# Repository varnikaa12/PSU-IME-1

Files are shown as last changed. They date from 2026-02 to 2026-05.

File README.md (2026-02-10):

# PSU-IME-1

The Harold & Inge Marcus Department of Industrial & Manufacturing Engineering at The Pennsylvania
State University is launching a new course in industrial automation and robotics. They are seeking a low-
cost, open-source, and modular tabletop training platform that supports hands-on learning in industrial
control systems, programmable logic controllers (PLCs), system integration, and digital twins while
currently lacking an affordable, modular physical platform for lab instruction. The department's existing
commercial training devices provide strong functionality but are too expensive, closed, and difficult to
modify or repair, limiting their suitability for long-term academic use and iterative student prototyping.
The student team will design and prototype an MVP tabletop production cell that sorts small colored
cylinders representing workpieces in a manufacturing line. Key requirements include modular and
reconfigurable mechanical design, predominantly 3D-printed or easily fabricated components, low
assembly complexity, 24V PLC compatibility using ladder logic via OpenPLC on RevPi hardware,
minimized custom electronics, and sourcing of all major components from established suppliers. In-scope
activities include mechanical design using primarily 3D-printed components, integration of 24 V
electrical hardware aligned with IEC 61131-2/3, PLC-based control logic, industrial sensor integration,
and development of a digital twin in ProtoTwin. Stretch goals include multi-size LEGO sorting, a bulk
hopper with automatic singulation, and interoperability with other tabletop cells to create an end-to-end
automated workflow.
Core deliverables include: (1) a working physical prototype suitable for classroom demonstrations, (2)
complete open-source documentation including CAD, bill of materials, assembly drawings, wiring
diagrams, and source code, and (3) a validated ProtoTwin model of the system. Key budget requirements
include a target build cost of approximately $100 per unit with an absolute maximum of $500. Expected
benefits include substantial cost reduction relative to commercial trainers, improved instructional quality
through hands-on interaction with industrial hardware, reduced setup and maintenance effort, and a
flexible open-source platform that future cohorts can modify, repair, and extend. The project is planned
for 15 weeks, starting January 12th and ending by May 3rd with the Capstone Showcase and Program
Closeout Review.

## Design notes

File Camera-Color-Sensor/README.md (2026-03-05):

# Camera Color Sensor & Recognition for Revolution Pi

This system provides high-accuracy real-time color recognition using a Random Forest model. It is designed to relay color data to a **Revolution Pi (RevPi)** via **Modbus TCP**, allowing for integration with **CODESYS** and industrial ladder logic.

## Key Features

- **Advanced AI Model**: Uses a Random Forest Classifier trained on BGR and HSV features (Version 2.0).
- **Lighting Robustness**: HSV color space integration helps distinguish colors (like Red vs. Brown) in varying light.
- **Modbus TCP Integration**:
  - **`color_recognition.py`**: Runs on a PC, acts as a Modbus Server (Slave).
  - **`color_recognition_revpi.py`**: Runs on the RevPi, acts as a Modbus Client (Master).
- **Camera Selection**: Automatically identifies Windows device names (e.g., "Integrated Camera", "UC60 Video").
- **Visual Feedback**: Live feed includes a focus box, certainty percentage, and a color patch.

## Setup & Installation

### 1. Prerequisites
- Python 3.10+
- Modbus TCP enabled in CODESYS (if using RevPi)

### 2. Install Dependencies
```bash
pip install -r requirements.txt
```

### 3. Training the Model
1. Place your categorized images in the `dataset/` folder.
2. Run the training script:
   ```bash
   python train_model.py
   ```
   This generates `color_model.pkl` using the advanced feature extraction.

## Usage

### Local Testing (PC as Server)
Run this script to test the camera and host the Modbus data:
```bash
python color_recognition.py
```
- **Modbus Address**: The color ID is written to **Holding Register 0**.
- **Note**: Run as Administrator on Windows to allow port 502 access.

### Production (RevPi as Client)
Run this script on the RevPi to capture video and write to a PLC/CODESYS:
```bash
python color_recognition_revpi.py
```

## Color Mapping Reference
The following IDs are sent over Modbus to CODESYS:

| ID | Color | ID | Color |
|:---|:---|:---|:---|
| 1 | Red | 6 | Violet |
| 2 | Green | 7 | Black |
| 3 | Blue | 8 | White |
| 4 | Yellow | 9 | Grey |
| 5 | Orange | 10 | Brown |

## Project Structure
- `camera_utils.py`: Hardware-level camera discovery and naming.
- `train_model.py`: Random Forest training with HSV feature extraction.
- `color_recognition.py`: Primary PC-side script (Modbus Server).
- `color_recognition_revpi.py`: RevPi-side script (Modbus Client).
- `requirements.txt`: Project dependencies (OpenCV, Scikit-learn, pyModbusTCP).

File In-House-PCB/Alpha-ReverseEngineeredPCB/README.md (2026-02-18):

# Line Sorter

**Project Name:** Line Sorter  
**Project Version:** `#7c7d5a3e`  
**Project URL:** https://www.flux.ai/re7rovm/line-sorter  

Line Sorter is a 24 V field I/O board that interfaces a PLC with sensors and actuators, providing protected digital inputs, low‑side MOSFET outputs for inductive loads, and a buffered analog sensor output. [file:31]

---

## 1. Overview

- **Purpose:** Condition 24 V field signals and drive multiple “line” loads (such as solenoids or relays) under PLC control. [file:31]  
- **System context:** The board sits between a PLC and field devices, converting PLC I/O into robust, protected connections for sensors and actuators. [file:31]  
- **Current status:** Rev `#7c7d5a3e` design with mapped nets and driver stages as described below. [file:31]

---

## 2. System Architecture

The Line Sorter PCB is organized into three main functional blocks: power conversion, PLC‑side I/O, and field‑side drivers/sensors. [file:31]

- **Power path:** 24 V input enters through J1, passes a fuse (F1) and protection diodes (D1, D2), and is split into 24Va and 24Vs rails with bulk and high‑frequency decoupling via C1 and C4. [file:31]  
- **DC‑DC conversion:** A TPS54302 buck regulator (U2) converts the 24Vs rail down to a 9 V rail using L1, C8, and feedback resistors R25 and R26. [file:31]  
- **Auxiliary supply:** A 5V_AUX rail is derived from the 9 V rail through an LDO regulator, powering the analog buffer op‑amp (U3) used for the color sensor signal. [file:31]  
- **PLC interface:** Digital inputs from the field are conditioned and routed into PLC input pins on U1, while PLC output pins from U1 drive the gates of MOSFET low‑side drivers. [file:31]  
- **Field connections:** Loads (e.g., solenoids) connect to J9–J13, and a color sensor connects to J15; each output or sensor line has defined return paths and protection components. [file:31]

---

## 3. Electrical Specifications

- **Input supply:** 24 V nominal via J1, protected by F1 and diodes D1/D2, generating 24Va and 24Vs rails. [file:31]  
- **Intermediate rail:** 9 V rail generated by TPS54302 buck (U2) with L1 and C8. [file:31]  
- **Auxiliary rail:** 5V_AUX derived from 9 V by an LDO to power analog circuitry (U3). [file:31]  
- **Digital inputs:** Multiple 24 V field inputs (I1, I2, I3, I5, I6, I7) feeding PLC inputs on U1 through series diodes and resistors plus pulldown resistors. [file:31]  
- **Outputs:** Five low‑side MOSFET driver channels (Q1–Q5) switching 24Va loads on connectors J9–J13, with flyback diodes for inductive loads. [file:31]

(Exact currents, voltage ranges, and derating should be filled in once the component ratings and requirements are finalized.)

---

## 4. Files and Structure

(Adjust naming to your repo/Flux export.)

- `schematic/` – Schematic source and PDF  
- `pcb/` – Layout and 3D view  
- `manufacturing/` – Gerber, drill, fabrication notes  
- `assembly/` – BOM, pick‑and‑place, assembly instructions  
- `docs/` – Additional documentation, test notes, images

---

## 5. Connectors and Pinout

Fill in exact pin numbers and names from your schematic; the notes below describe the functional roles. [file:31]

### J1 – 24 V Power Input

- VIN (24 V nominal) passes through F1 and protection diodes D1/D2 to form the 24Va/24Vs rails. [file:31]  
- GND connects to the board ground, shared with MOSFET source nodes and PLC 0 V returns. [file:31]

### J3–J8 – Digital Field Inputs (I1, I2, I3, I5, I6, I7)

Each connector provides a 24 V input channel plus a dedicated 0 V return for a PLC input. [file:31]

- Field input pin: goes through a series diode (D8–D13) and resistor (R11–R16) into a PLC input pin on U1 (pins 5–11). [file:31]  
- 0 V return: matches a specific 0 V node (e.g., I1_0V, I2_0V, etc.) and ties back to system GND. [file:31]  
- Pulldown resistors R17–R22 provide defined off‑state behavior for the PLC inputs. [file:31]

### J9–J13 – Line Outputs (Low‑Side Driven Loads)

Each connector is associated with one MOSFET driver Q1–Q5. [file:31]

- Pin 1: 24Va high side supply for the load. [file:31]  
- Pin 2: Switched low side (Qx_SW), which is the MOSFET drain node (Qx:D) and the load return. [file:31]  
- Each MOSFET source (Qx:S) connects to GND and Qx_0V net. [file:31]  
- Flyback diode Dx clamps Qx_SW to Qx_0V to protect against inductive kick when switching off inductive loads. [file:31]

### J15 – Color Sensor Connector

- 9 V supply and GND rails provided for the external color sensor module. [file:31]  
- SENS_SIG returned to the board, buffered by op‑amp U3, and routed to PLC analog input node PLC_I4_AIN. [file:31]

(Add exact pin numbering and orientation once you finalize the schematic annotation.)

---

## 6. PCB Manufacturing Notes

(To be completed with actual mechanical data.)

- Board size: `WIDTH × HEIGHT mm`  
- Layers: `N` layers  
- Material/thickness: e.g., FR‑4, 1.6 mm  
- Copper weight: e.g., 1 oz outer, 1 oz inner  
- Finish: ENIG / HASL  
- Mask/silkscreen: colors and sides  
- Special requirements: appropriate creepage/clearance for 24 V, mounting holes, slots, etc.

---

## 7. Assembly Information

- **BOM:** Contains F1, D1–D13, U1, U2, U3, Q1–Q5, L1, C1, C4, C8, feedback and gate resistors, and connectors J1–J15. [file:31]  
- **Polarity/orientation:**  
  - Diodes D1–D13, MOSFETs Q1–Q5, and electrolytic capacitors must be oriented correctly. [file:31]  
  - ICs U1, U2, U3 must align with their pin‑1 indicators. [file:31]  
- **Assembly order:** Recommended to populate small SMD parts first (resistors, diodes, ICs), then larger components and connectors (L1, terminals Jx, fuse F1). [file:31]

---

## 8. Functional Description

- **Power stage:** 24 V input is fused and protected before feeding 24Va/24Vs; TPS54302 buck converts 24Vs to 9 V, and an LDO produces 5V_AUX for analog circuitry. [file:31]  
- **Digital inputs:** Field 24 V inputs are diode‑ and resistor‑limited before the PLC, with pulldowns to ensure defined off levels. [file:31]  
- **Output drivers:** PLC outputs drive MOSFET gates via series resistors R1–R5, with gate pulldowns R6–R10; MOSFET drains switch the load low side at J9–J13, and diodes D3–D7 provide flyback protection. [file:31]  
- **Analog sensor path:** A color sensor on J15 is powered from 9 V and GND, with its signal buffered by U3 and sent to PLC analog input PLC_I4_AIN. [file:31]

---

## 9. Testing and Bring‑Up

- Verify no short between 24 V and GND at J1 before powering.  
- Power up with a current‑limited 24 V supply and confirm the presence of 9 V and 5V_AUX rails. [file:31]  
- Check PLC input channels by applying known 24 V signals to J3–J8 and observing corresponding PLC inputs. [file:31]  
- Test each line output by connecting a dummy load (e.g., lamp or resistor) on J9–J13 and toggling the corresponding PLC output, watching for correct switching and absence of over‑current or overheating. [file:31]

---

## 10. Tools and License

- **CAD tool:** Flux (project URL above).

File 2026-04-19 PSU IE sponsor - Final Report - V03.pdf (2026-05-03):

# PSU IME Capstone #1

### Final Report

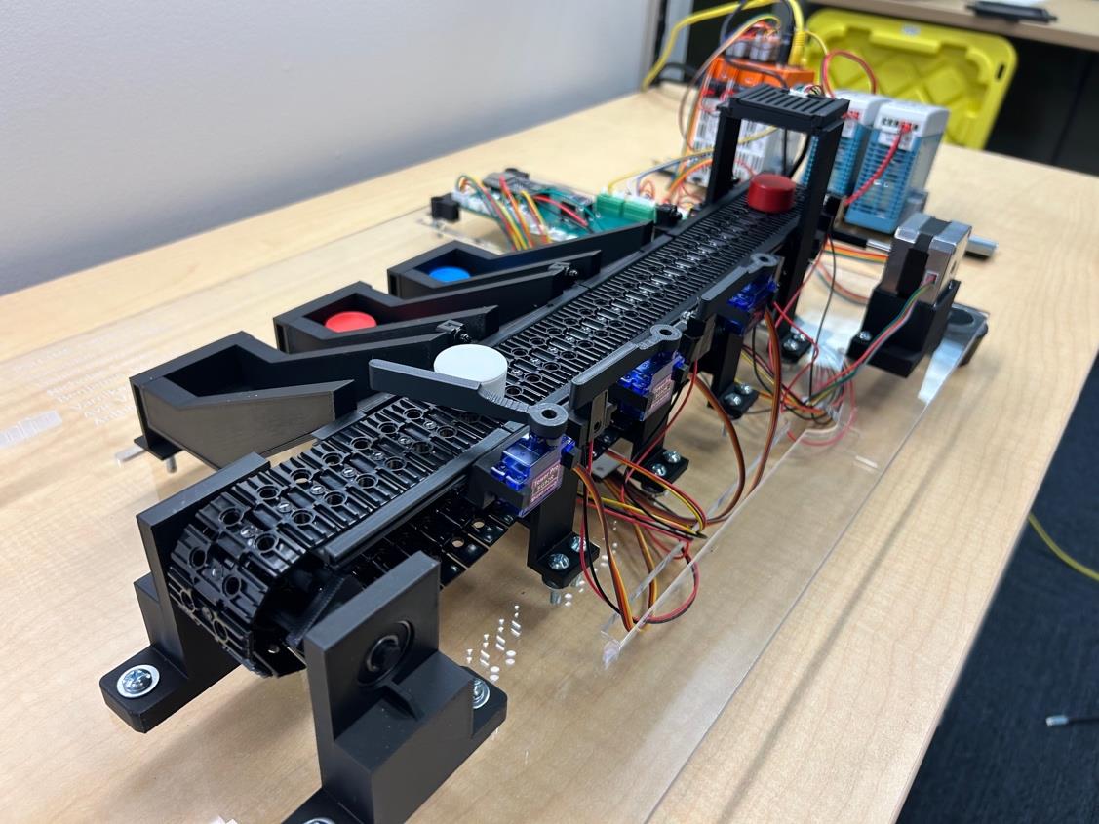
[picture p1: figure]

2026-04-26

Figure 1. Final CAD Assembly

Submitted to:
Prof. Brian Thomas Zajac
344 Leonhard Building
The Pennsylvania State University Park, PA 16802
Submitted by:
Nicholas Savoca, Benjamin Johnston, Daniel Pellizzari, Varnikaa Arora, Anthony Ottaviano, Avie Vasantlal

Advisor:
Prof. Brian Thomas Zajac

Y N
☐ | ☒ | Intellectual Property Rights Agreement Applies
☐ | ☒ | Non-Disclosure Agreement Applies

# Executive Summary

The Harold & Inge Marcus Department of Industrial & Manufacturing Engineering at The Pennsylvania State University is launching a new course in industrial automation and robotics. They are seeking a low-cost, open-source, and modular tabletop training platform that supports hands-on learning in industrial control systems, programmable logic controllers (PLCs), system integration, and digital twins while currently lacking an affordable, modular physical platform for lab instruction. The department's existing commercial training devices provide strong functionality but are too expensive, closed, and difficult to modify or repair, limiting their suitability for long-term academic use and iterative student prototyping.

The student team designed and prototyped an MVP tabletop production cell that sorts small colored cylinders representing workpieces in a manufacturing line. Key requirements include modular and reconfigurable mechanical design, predominantly 3D-printed or easily fabricated components, low assembly complexity, 24V PLC compatibility using ladder logic via OpenPLC on RevPi hardware, minimized custom electronics, and sourcing of all major components from established suppliers. In-scope activities include mechanical design using primarily 3D-printed components, integration of 24 V electrical hardware aligned with IEC 61131-2/3, PLC-based control logic, industrial sensor integration, and development of a digital twin in ProtoTwin. Stretch goals include multi-size LEGO sorting, a bulk hopper with automatic singulation, and interoperability with other tabletop cells to create an end-to-end automated workflow.

Core deliverables include: (1) a working physical prototype suitable for classroom demonstrations, (2) complete open-source documentation including CAD, bill of materials, assembly drawings, wiring diagrams, and source code, and (3) a validated ProtoTwin model of the system. Key budget requirements include a target build cost of approximately $100 per unit with an absolute maximum of $500. Expected benefits include substantial cost reduction relative to commercial trainers, improved instructional quality through hands-on interaction with industrial hardware, reduced setup and maintenance effort, and a flexible open-source platform that future cohorts can modify, repair, and extend. The project is planned for 15 weeks, starting January 12th

and ending by May 3rd
with the Capstone Showcase and Program Closeout Review.

In order to be efficient, we divided our group into three subgroups, which were Mechanical, Electrical, and Software, which enabled parallel development. The design process utilized decision matrices to prioritize cost-efficiency and modularity. The team delivered a physical prototype mounted on a laser-cut acrylic baseplate with a custom 24V PCBA, modular 3D-printed components, and a CODESYS Function Block control program deployed on a RevPi. A few of the stretch goals were reserved for future development, but primary deliverables of CAD files, BOM, and source code were completed and uploaded to an open-source GitHub repository. Financially, the project achieved its goal of remaining under the $500 maximum budget constraint, achieving a final per-unit cost of $325.97. This represents an approximate 76.5% cost reduction compared to the $1,387 commercial Fischertechnik equivalent (Studica, n.d.), successfully proving the viability of a highly affordable, open-source educational platform.

# Table of Contents

# 1.0 Introduction

The Harold & Inge Marcus Department of Industrial & Manufacturing Engineering (IME) at Penn State emphasizes hands-on laboratory experiences that prepare students to design, control, and improve modern manufacturing systems (About the Department, 2021). To support a new course in industrial automation and robotics, the sponsor seeks a tabletop training platform that exposes students to realistic industrial technologies such as sensors, actuators, and programmable logic controllers (PLCs), while remaining low-cost, open-source, and easy to modify for future use. As part of this effort, the project will adapt and “open up” the existing Fischertechnik line sorter concept by recreating a functionally similar line using predominantly 3D-printed and readily sourced components, and by releasing all CAD, electrical documentation, and control code as open-source artifacts so that other instructors and students can study, replicate, and extend the design.

Existing commercial tabletop “smart factory” trainers, including proprietary Fischertechnik-based systems (fischertechnik, 2016), demonstrate that compact production cells are effective for teaching PLC programming, sequencing, and system integration, but these systems are relatively expensive and closed, limiting their ability in iterative student experimentation and long-term maintainability within an academic setting. The proposed project addresses this gap by developing a modular tabletop production cell that sorts small colored cylinders, representing workpieces in a discrete manufacturing line, implementing as an open-source reinterpretation of the Fischertechnik-style line sorter. The system focuses on being reconfigurable, predominantly 3D-printed mechanical components, having a simple assembly, and compatibility with standard 24 V PLC hardware, so students can assemble, troubleshoot, and extend the platform within the course.

To ensure reproducibility and student access to reference materials, the project leverages established open documentation repositories for each core technology. The RevPI DIO, AIO, and Core SE hardware documentation is available through the RevolutionPi GitLab repository and official product manuals (RevolutionPi, 2025). OpenPLC Editor IDE documentation and runtime source code reside in the OpenPLC Github repository, providing complete transparency for ladder logic and function block programming (OpenPLC, 2025). ProtoTwin digital twin software references are hosted in their developer documentation portal, supporting seamless hardware-digital twin integration (ProtoTwin, 2025). Finally, the baseline Fischertechnik sorting line module specifications, including wiring diagrams and I/O maps, are documented in the official technical datasheet (fischertechnik, n.d.-a).

A key result from the background research is the importance of aligning both the hardware and software of the platform with industrial standards for PLC systems. IEC 61131-2 defines the electrical and environmental requirements for PLC equipment, including the use of 24 V DC as a standard control voltage for inputs and outputs, which supports safe, reliable integration of field devices with industrial controllers (IEC 61131-2, 2025). In parallel, IEC 61131-3 defines the basic software architecture and programing languages for programmable controllers, specifying a unified suite of languages such as ladder diagram, function block diagram, and structured text, along with standard data types and program organization units (IEC 61131-3, 2025). Taken together, these standards lead directly to a specific requirement for the project. The tabletop cell shall be controllable by a 24 V PLC that complies with IEC 61131-2 and supports at least one IEC 61131-3 language, and the control logic and documentation shall be organized according to the IEC 61131-3 model of tasks, programs, and function blocks with source/sink style DIO aligned to the Fischertechnik model, sinking inputs accepting current from sensors to PLC ground, sourcing outputs providing +24V to actuators (fischertechnik, n.d.-a). Aligning the open-source line sorter with IEC 61131-2 and IEC 61131-3 ensures that the students’ experience with the training platform is directly transferable to industrial PLC hardware and software environments they will encounter in professional practices.

# 2.0 Problem Statement

The problem this project addresses was the need to design a low cost, reconfigurable tabletop automation system that can provide industry relevant information while remaining accessible and extensible for future academic changes.

The project focused on developing a minimum cost tabletop assembly line capable of sorting small colored cylindrical workpieces using a 24 V industrial PLC, sensors, actuators, and a moving conveyor belt. The solution integrated mechanical, electrical, and control systems into a cohesive platform that supports the required learning objectives. In scope activities initially included mechanical design using primarily 3D printed components, PLC based control logic, industrial sensor integration, and
development of a digital twin using ProtoTwin (ProtoTwin, 2025). However, throughout the course of the project. Control using OpenPLC was removed, and the Digital Twin was changed to be a simulation. Out of scope elements include full scale industrial automation, the ability to sort LEGO bricks, and high speed or high load manufacturing operations.

The primary design element and degree of freedom in this project can be found in the overall design of the tabletop automation device. While the function is fixed (sorting-colored workpieces), our team has created flexibility in mechanical layout, module interfaces, sensing and actuation methods, PLC logic structure, and the level of precision for the digital twin. This openness allowed multiple design concepts to be explored and evaluated, from which a final solution was selected based on performance, cost, usability, and academic value.

The expected benefits of the proposed solution include significant cost reduction compared to commercial training systems, improved instructional quality through physical interaction with real industrial hardware, reduced setup and maintenance complexity, and increased flexibility for future course integration. From a performance perspective, the system is capable of reliable sorting operations suitable for classroom use. From a quality perspective, the device will emphasize robustness, repeatability, and clear documentation. In terms of time and efficiency, the modular design is expected to reduce setup, reconfiguration, and troubleshooting effort for both students and laboratory staff.

To evaluate the overall project success, the Key Performance Indicator (KPI) was defined as the total system build cost per unit. This KPI directly aligns with the primary project driver, affordability, and reflects the system’s scalability for educational development. The target threshold for success is a total build cost of $100 per unit, with an absolute maximum allowable cost of $500 per unit. Meeting this KPI ensured that the solution meaningfully improves upon the current commercial devices and enables widespread adoption with the academic community.

Several stakeholders are affected by or have a vested interest in the outcome of this project. Primary stakeholders include faculty members, students, laboratory staff, and future course designers. Based on these stakeholders' perspectives, the following needs have been identified and have been the foundation for subsequent engineering requirements:

1. Affordability: The system should be low cost to allow multiple units to be used in a single lab.
2. Modularity: The platform should allow components to be rearranged, replaced, or expanded upon.
3. Comprehensive Documentation: The solution should include clear and complete documentation.
4. Ease of Use and Maintenance: The system should be easy for staff and students to assemble and operate on

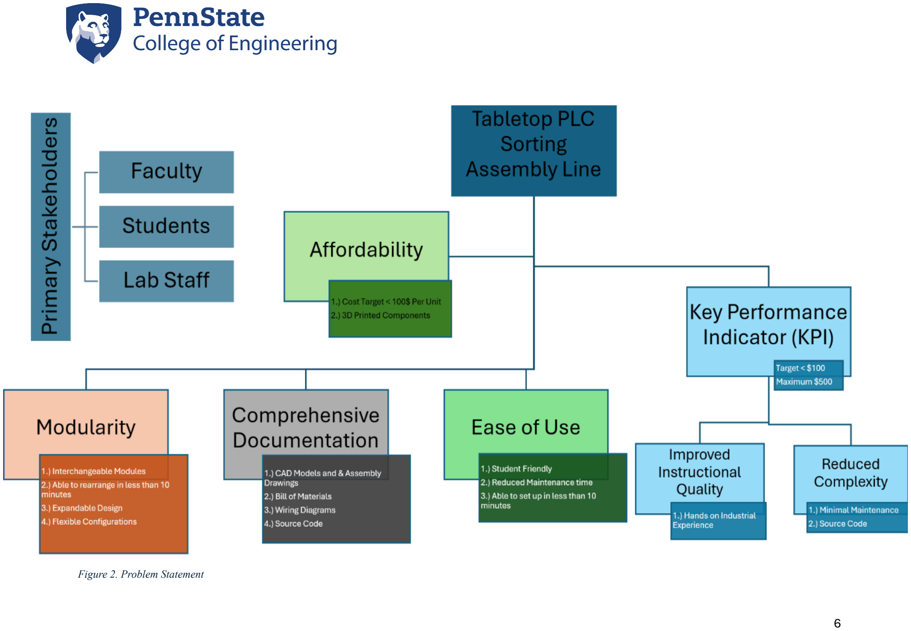
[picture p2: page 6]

6

Figure 2. Problem Statement

# 3.0 Project Requirements

The requirements table shown below represents our team’s original view of what was expected of the final prototype by the end of the project date, and no revisions were made to the requirements from the original Statement of Work. It identifies the most critical design and programming elements, which include the cost, performance of the prototype, level of modularity of the final design, user safety, and the digital twin requirements. Also shown in the table are some of the “stretch” goals, which represent elements that the final design should implement if time and budget constraints allow for it. These included, being largely 3D printed and having the capability to sort LEGO Brick.

During the Alpha and Beta prototype stages, the most challenging requirement to address was creating standard mechanical and electrical connectors to enable modularity. Several of the stretch goals also presented challenges due to the time and amount of work required to accomplish them. These included the goals of incorporating a hopper and enabling compatibility with 120 V AC input, both of which were ultimately not achieved within the project timeframe.

In the third columns of Table 1 and Table 2, each requirement is categorized as to which part of the project it addresses. These categories show how the project addressed the different needs of the stakeholders including the sponsor regarding the constraints, budget, and schedule, and the public for the environmental, social, and safety requirements.

The final columns of Table 1 and Table 2 provide additional context for the requirements. This column describes each requirement in more detail where necessary, as well as discussing where the requirement originated from, typically from the sponsor.

All requirements have been incorporated into the Verification Cross Reference Matric found in Section 6.1 in Tables 6, 7, and 8.

Table 1. Table of Requirements Version 2, Last Modified 2/1/26.

# | Requirement | Type | Additional Details

1 | Cost per unit shall be between ~$100 and ~$500 | Economic | Provided by the Sponsor
2 | Device shall be designed on 24V standard system architecture | Standard | The IEC defines 24 V DC as the standard Voltage to be used with PLCs. (IEC 61131-2)
3 | Device shall be programmed with Function block programming. | Constraint | IEC 61131‑3 defines the standard programming languages, data types, and program organization units (POUs) for industrial PLCs (IEC 61131‑3)
4 | Structure should be largely 3D Printed out of common materials, such as PLA. | Resources, Global | Provided by the Sponsor
5 | Final product shall be Open Sourced with BOM, CAD models, and source code provided on GitHub. | Global, Social | Provided by the Sponsor
6 | The design shall have a standard mechanical and electrical connector to enable modularity by extending workflows, and by allowing component replacement in under 30 minutes. | Constraint | In the case that parts break, they can be easily replaced. The sponsor requested that the design must be easy to build upon and manipulate.
7 | Device shall be able to sort blue, white, and red workpieces that are 1 inch in diameter and half an inch in height. | Constraint | Provided by the Sponsor
8 | Final Prototype shall be functional with a demo program. | Constraint | Provided by the Sponsor
9 | All Major components should be sourced from PSU Suppliers. | Constraint/Economic | Required to readily access the team's budget, and provided by the Sponsor
10 | A digital twin of the final prototype shall be provided utilizing ProtoTwin | Constraint | Provided by the Sponsor
11 | Final prototype shall be provided with all wires insulated and grounded, as well as pinch points minimized and labeled. | Public Health, Safety, and Welfare | Given the Open-Source nature of the project and its future use in teaching, it must be safe to assemble and operate.

Table 2. Table of Requirements Version 2, Last Modified 2/1/26.

# | Requirement | Type | Additional Details

12 | Final prototype shall be provided with all pinch points minimized and labeled. | Public Health, Safety, and Welfare | As above, since this project will be used in teaching and Open-Sourced, it must be safe to assemble and operate.
13 | Components shall be replaceable in under an hour in the event of failure. | Environmental | Replaceable parts help keep the lifetime cost of the product down, as well as increasing its lifespan.
14 | A basic simulation of the design shall be provided by the end of the beta stage of the project. | Schedule | Not a true digital twin, but a basic simulation showing progress made in programming and CAD at this point in the project.
15 | Final prototype should be able to sort square/rectangular LEGO bricks and plates from 1x1 up to 2x4 studs in size when placed with studs facing upwards. LEGO pieces should be blue, red, or white. | Constraint | Stretch goal
16 | Final prototype shall be capable of sorting workpieces at a rate of 15 pieces per minute. | Constraint | Sorting speed/throughput
17 | Final prototype shall have a sorting accuracy of 95%. | Constraint | Only 1 in every 20 pieces would be sorted incorrectly.
18 | Final prototype should be able to sort pieces being automatically dispensed from a bulk hopper. | Constraint | Stretch goal, pieces would be dispensed 1 at a time.
19 | Final prototype should be compatible with 120V AC Input. | Constraint | Stretch goal, this would eliminate the need for a power supply, which would significantly reduce overall cost.
20 | Final prototype shall have a standard footprint no larger than that of the Fischertechnik device. | Constraint | Fischertechnik footprint is 15 inches by 10.25 inches.
21 | Final prototype shall follow the DIO source/sink layout from the Fischertechnik Device. | Constraint | This will help ensure that individuals experienced with the Fischertechnik device will be able to use our prototype.

## 3.1 Risk Management

The Hazard Table and Rick Matrix, Table 3 and Figure 3 respectively, presented in this section were developed during the Preliminary Design Review to identify, prioritize, and mitigate the most significant risks to the project’s success. Table 3 summarizes each hazard by type, proposed mitigation, strategy, likelihood, severity, and total risk score. Figure 3 displayed the Risk Matrix, which plots each hazard before and after mitigation to visualize the reduction in the overall exposure score.

Of the risks identified, Risk ID 3 carried the highest pre-mitigation score of 9 and proved to be the most consequential over the course of the project. Despite our efforts, PCB fabrication, express shipping costs, as well as the culmination of other minor components, caused the actual single prototype cost to go over the target KPI of $100. Risks 2a and 4 also occurred during the project. These were attempted to be mitigated by early integrating checkpoints and prioritizing PSU sourced suppliers however shipping delays, from PSU sourced suppliers, for the PCB presented full hardware-software integration until late in the project, limiting the ProtoTwin (ProtoTwin, 2025) to a functional simulation rather than a true digital twin in addition to causing delays for the testing phase. Risk 1a was partially realized as the system achieved a 97.2% color sorting accuracy but fell short of the 15 pieces per minute throughput requirement due to PLC logic limitations; the PLC control program was unable to keep track of multiple pucks with the same counter block after passing through the camera sensor. Risk 5a was successfully mitigated with no safety incidents occurring during assembly. The remaining low score risks did not affect the project’s outcome.

Table 3. Hazard Table

ID # | Type | Hazard | Mitigation | Likelihood | Severity | Total Risk Score
1a | Technical | Sorting Accuracy or Throughput not met | Conduct beta testing and iterative calibration | 2 | 3 | 6
1b | Technical | Performance risk (post mitigation) | | 1 | 3 | 3
2a | Schedule | Integration delays between hardware & digital twin | Establish early integration checkpoints | 2 | 3 | 6
2b | Schedule | Integration delay (post mitigation) | | 1 | 3 | 3
3 | Economic | Prototype exceeds $100 KPI | Maintain updated bill of materials and prioritize off the shelf components | 3 | 3 | 9
3a | Economic | KPI post mitigation | | 2 | 2 | 4
4 | Global | Supply chain delays for components | Prioritize PSU-sourced suppliers and order long-lead items early | 2 | 3 | 6
4a | Global | Supply chain delays (post mitigation) | | 1 | 3 | 3
5a | Public Safety | Conveyor or actuator pinch points | Minimize and label pinch points as well as include safety information | 2 | 3 | 6
5b | Public Safety | Pinch point injury (post mitigation) | | 1 | 3 | 3
6 | Cultural/Societal | Open-source system perceived as lower quality | Emphasize IEC 61131-2/3 compliance and professional documentation | 1 | 2 | 2
7 | Environmental | Material waste from iterative 3D printing | Optimize CAD before printing and recycle failed prints | 2 | 1 | 2
8 | Public Welfare | Poor documentation reduces usability | Publish complete GitHub documentation and labeled diagrams | 1 | 2 | 2
9 | Public Health | Electrical exposure or wiring issues. | Insulate all wiring and follow 24V IEC standards | 1 | 3 | 3

Likelihood

1

2

3

1
2 | 3

Severity

| 6,8 | 1b,2b,4a,5b,9
7 | 3a | 1a,2a,4,5a
| | 3

Figure 3. Risk Matrix

# 4.0 Approach

We approached the project by first studying the existing Fischertechnik device (fischertechnik, 2016), as well as familiarizing ourselves with CODESYS (CODESYS, 2026), and Function Block/Ladder Logic programming. This step was essential to understanding our task, as well as for brainstorming ways in which we could innovate with our device. During this time, we recognized a need for more distinct sub teams for the three main elements of the project, Mechanical, Electrical, and Programming. Mechanical would be responsible for designing and assembling the main structure of the device, including the belt, electrical mounts, and baseplate. Electrical would be responsible for creating the PCBA needed to properly power and connect the motors and sensors to the RevPi (RevolutionPi, 2025). Programming would be responsible for adapting existing code for the Fischertechnik device (fischertechnik, 2016) to work with the selected components, as well as creating a digital “twin” to potentially aid in “virtual commissioning” of the device before physical creation.

The ideation process was primarily focused on looking for ways that the prototype could improve upon the Fischertechnik device (fischertechnik, 2016) by being more modular and affordable, while keeping the operation of the device very similar. This brainstorming led the team to several key design variations from the Fischertechnik design (fischertechnik, 2016). Instead of using pneumatic pushers to derail pucks, it was decided to use servos to lower both the cost and complexity of the design. Another key design variation was using a USB camera for color sensing, rather than a phototransistor. This creates the future capability to use machine learning to sense things other than color, such as size, shape, etc. Provided below is the decision matrix that was used to choose which camera we used for the color sensing. Overall, it was decided to use the DFRobot Fit0729 camera module as the camera sensor. Though it was slightly more expensive than other options, this camera module provided the highest resolution sensor, while allowing for connectivity through a 4-pin connector or USB-A, allowing for direct integration into the PCB or rapid prototyping by connecting to the RevPIs USB port (RevolutionPi, 2025).

| Weight | RPi Camera 2 | ESP32 Timer Camera | DFRobot Fit0729 | Adafruit OV5640 Breakout Board
Cost | 4 | 5 | 5 | 4 | 5
Sensor Resolution | 1 | 5 | 3 | 5 | 4
Ease of Use (“plug and playability”) | 4 | 0 | 3 | 5 | 1
Ease of Use PCB Implementation | 3 | 0 | 4 | 5 | 4
Total Score | | 25 | 47 | 56 | 40
Table 4. Camera Decision Matrix

The team’s concept selection process was focused on the mechanical portion of the project, particularly in deciding on how the servos should be used to derail pucks from the belt. The three concepts the team decided between were a simple lever arm, a pusher mechanism using a mechanical linkage, and the pneumatic pusher used by the Fischertechnik device (fischertechnik, 2016).

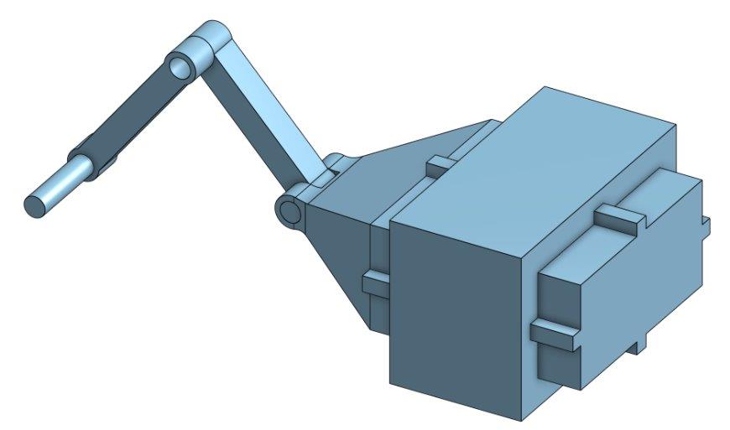
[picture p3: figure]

Figure 4. Linked Pusher CAD

| Weight | Lever Arm | Linked Pusher | Pneumatic Pusher
Cost | 3 | 10 | 8 | 3
Similarity to existing design | 2 | 3 | 7 | 10
Complexity | 1 | 4 | 3 | 3
Total Score | | 40 | 41 | 32
Table 5. Derailer Decision Matrix

From this decision matrix it was initially decided to go with the Linked Pusher, however, after further consulting with our sponsor, the team decided that we had weighed the “Similarity to existing design” too heavily and pivoted to a Lever Arm design for simplicity. Other concepts that were considered were regarding the belt. Initially, we were planning to make a modular belt or buy a belt from an automation supplier. However, it was decided that we would use a LEGO belt, which was affordable, and easy to make shorter or longer based on the number of bays.

Following ideation and concept selection, we produced our Alpha Prototypes. These were high level prototypes intended to demonstrate the basis of our planning and understanding of the task. The Mechanical team created a top-down model of our intended device layout, as well as several 3D CAD designs for our derailers, shown above in Figure 4. The electrical team created a preliminary schematic for the PCB, shown in Figure 5. The Programming team created a ProtoTwin (ProtoTwin, 2025) simulation to demonstrate their increasing knowledge of Function Block programming and ProtoTwin (ProtoTwin, 2025), as a “Hello World” exercise. These prototypes helped to align expectations with our sponsor, as well as ensure that the project was proceeding as planned at this point in the semester.

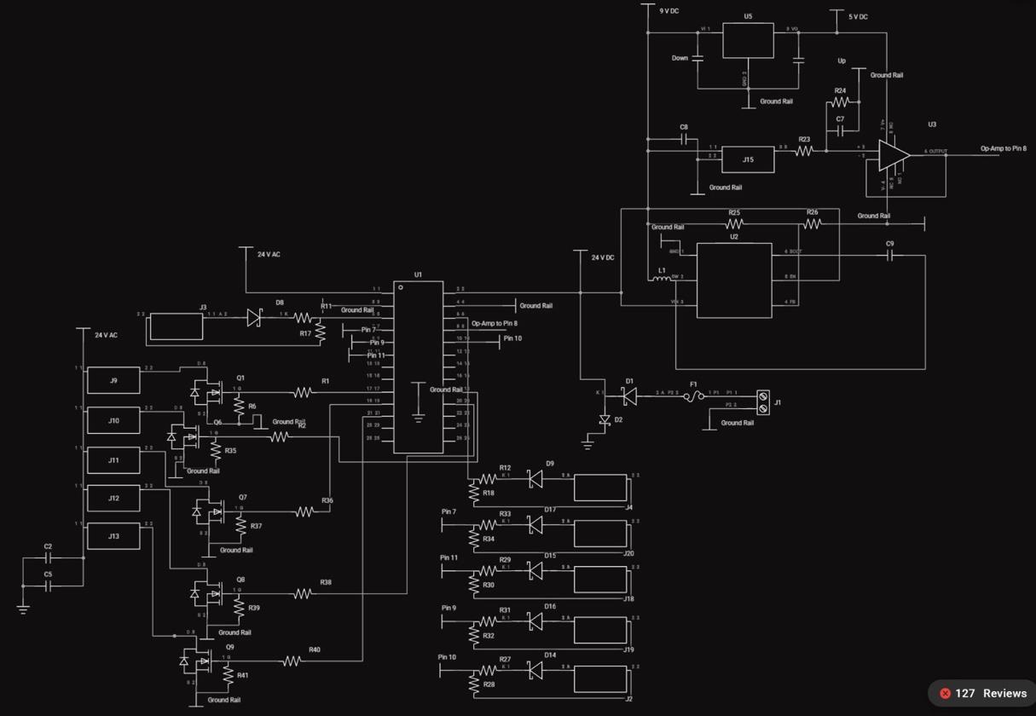
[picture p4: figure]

Figure 5. PCBA Schematic Alpha Prototype

Following the Alpha Prototypes and the feedback received from the sponsor, work began on the Beta Prototypes. These included significantly greater detailed designs that showed a more representative look at what our final prototype could look like. For the Mechanical team, this included a CAD model of the system at the time showing a potential orientation for the servo motors, shown in Figure 6. This also included the rail connector system which allows for easy component replacement of most main components. This model was still missing several key components, such as mounting solutions for the camera, break beams, and microswitch mount. However, this beta prototype provided a foundation on which would evolve into our Final Prototype.

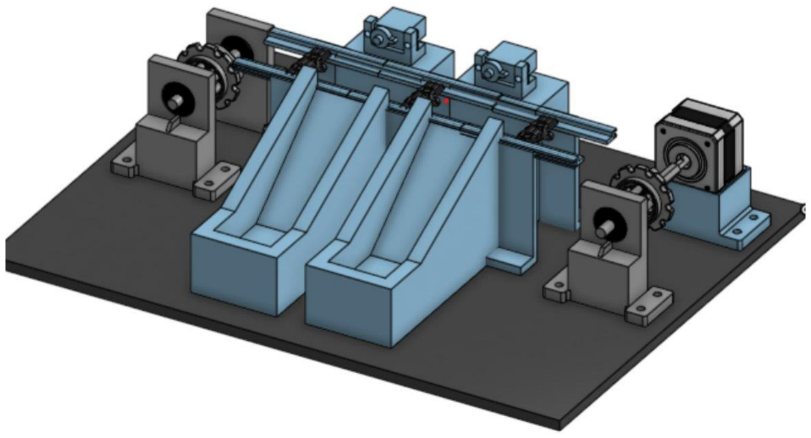
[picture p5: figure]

Figure 6. 3D CAD Model Beta Prototype

The Electrical Beta was a far more complete schematic of our custom PCBA, designed with our ordered components in mind. It incorporated uniform connectors to interface with the board in the form of JST-XH connectors. It also featured a thermal evaluation test where the board was tested through a power delivery analysis simulation in order to find hot spots on the board. This resulted in the movement of several high power-consuming integrated circuits on the board to cooler spots to reach safe operational temperatures. The programming Beta was a more representative ProtoTwin simulation (ProtoTwin, 2025), demonstrating our implementation of color detection with Function Block programming. These Beta prototypes proved crucial towards identifying potential issues with our designs, such as 3D Print tolerances, and thermal control on the PCBA.

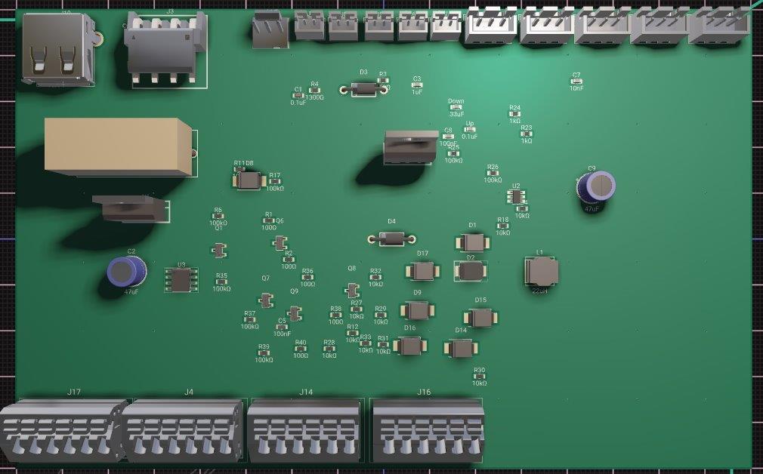
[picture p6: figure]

Figure 7. PCBA Beta Prototype

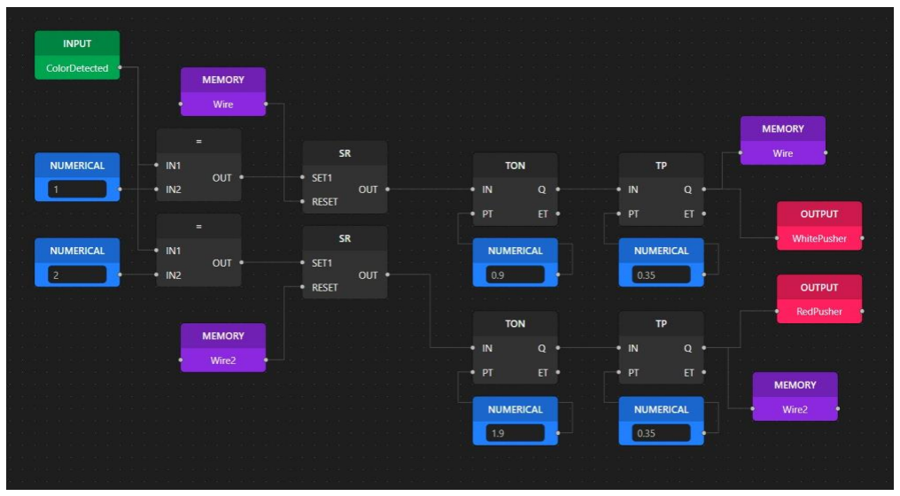
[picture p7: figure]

Figure 8. ProtoTwin Beta Prototype Function Block Code

## 4.1 Schedule Narrative

The Gantt Chart displays the six different phases of the project. Within the first two phases, Empathize and Define, the most important tasks were establishing contact with the sponsor and alumni coach and completing the Statement of Work. This document summarized the key deliverables and set the standards the project needed to meet by the end of the program.

Following this, the Ideate phase reflects the sub-team strategy discussed in the Approach section of this report. The group was divided into three teams: Mechanical, Electrical, and Software. This allowed the group to work in parallel with each team’s respective Alpha prototypes. Key milestones during this phase included the use of Decision Matrices to select the camera sensor and derailer mechanism. This parallel structure proved to be one of the most effective decisions made during the project, allowing all three prototypes to be complete efficiently enabling the team to move on to the Prototype phase without any delays.

Within the Prototype phase, the most significant accomplishment was the construction of the Beta Prototypes. Each sub-team continued working in parallel, producing more detailed and representative designs that laid the groundwork for final development. During this time, the team encountered delays due to disruptions in the ordering and delivery of key electrical components. These were mitigated by continuing development on unaffected areas of the project and advancing to subsequent tasks where possible, allowing the team to remain largely on schedule despite the setbacks.

The Test phase brought the most complications for the team. Delayed arrival of the PCBA and its associated electrical components created a significant bottleneck, as the mechanical and software components could not be fully integrated or tested until the board arrived. This meant that issues in both the mechanics and software went unidentified for longer than anticipated. Additionally, the full mechanical assembly of the Sortinator required extensive trial and error to achieve tolerances that allowed all moving parts to fit together properly while still being hand-assembled. This included numerous iterations of the conveyor belt support legs and the baseplate. To push through these challenges, the team delegated tasks strategically, ensuring that each sub-team was always making progress in whatever area was accessible to them at the time.

The Deliver phase encompasses final deliverables including the Showcase Poster, Final Reports, GitHub finalization, Final CAD Assembly and BOM, and the Program Closeout Review. As of April 26th ,
each of these deliverables have been submitted.

As mentioned, the program schedule featured a number of changes and additions over the course of the project. These changes are highlighted in blue on the Gantt chart and reflect the team's response to unforeseen complications, particularly during the Test phase. Added tasks include Mechanical Assembly, Finalize and Order PCB, CAD Assembly for ProtoTwin (ProtoTwin, 2025), Connect PCB, Adding Functionality to the CAD Model, Programming PLC with New Function Code, PCB Connection and Test of Wiring, and Test Code on Sortinator. These additions do not reflect a lack of planning, but rather the team's willingness to adapt and take on additional work to ensure project success. In total, the team completed a considerable amount of work beyond what was outlined in the original proposal.

## 4.2 Individual Contributions

### Mechanical

Benjamin Johnston – Designed parts for the main structure, as well as tested and iterated upon them once they were printed. Also functioned as the team lead, organizing meetings and communicating with the Sponsor/Advisor and Alumni Coach.

Daniel Pellizzari – Designed parts for the main structure, aided in the testing and reiteration of printed parts. Also served as the Program Manager developing, tracking, and updating the project schedule as work progressed as well as ensuring the team remained on schedule.

Nicholas Savoca – Designed parts for digital twin as well as main structure. Aided in purchasing and assembly of required parts for prototypes. Put together final assembly as well as reviewed and edited documents for canvas submission.

### Electronical

Avie Vasantlal – Designed the PCB (Printed Circuit Board) to drive the Sortinator using 24V architecture and responsible for soldering and assembling the entire electrical system. Created the initial iteration of the computer vision color sensing using Python and aided in the adjustment needed to port it to
CODESYS (CODESYS, 2026). Aided in part selection needed for the prototypes and final iteration.

### Software

Varnikaa Arora – Programming the ESP microcontrollers, adapting CAD models for the ProtoTwin (ProtoTwin, 2025) simulation, and testing new technologies which influenced decisions moving forwards. Managed GitHub repository and set up documentation for Fischertechnik (fischertechnik, 2016) and CODESYS (CODESYS, 2026). One of two editors for team deliverables.

Anthony Ottaviano – PLC Programming as well as development of the ProtoTwin simulation (ProtoTwin, 2025). Developed a Function Block Diagram control program for the Sortinator. Created digital simulation of the Sortinator and designed the control logic of the simulation in Function Block Diagram. Also served as the Treasurer, submitting orders and keeping track of project expenditures.

# 5.0 Schedule

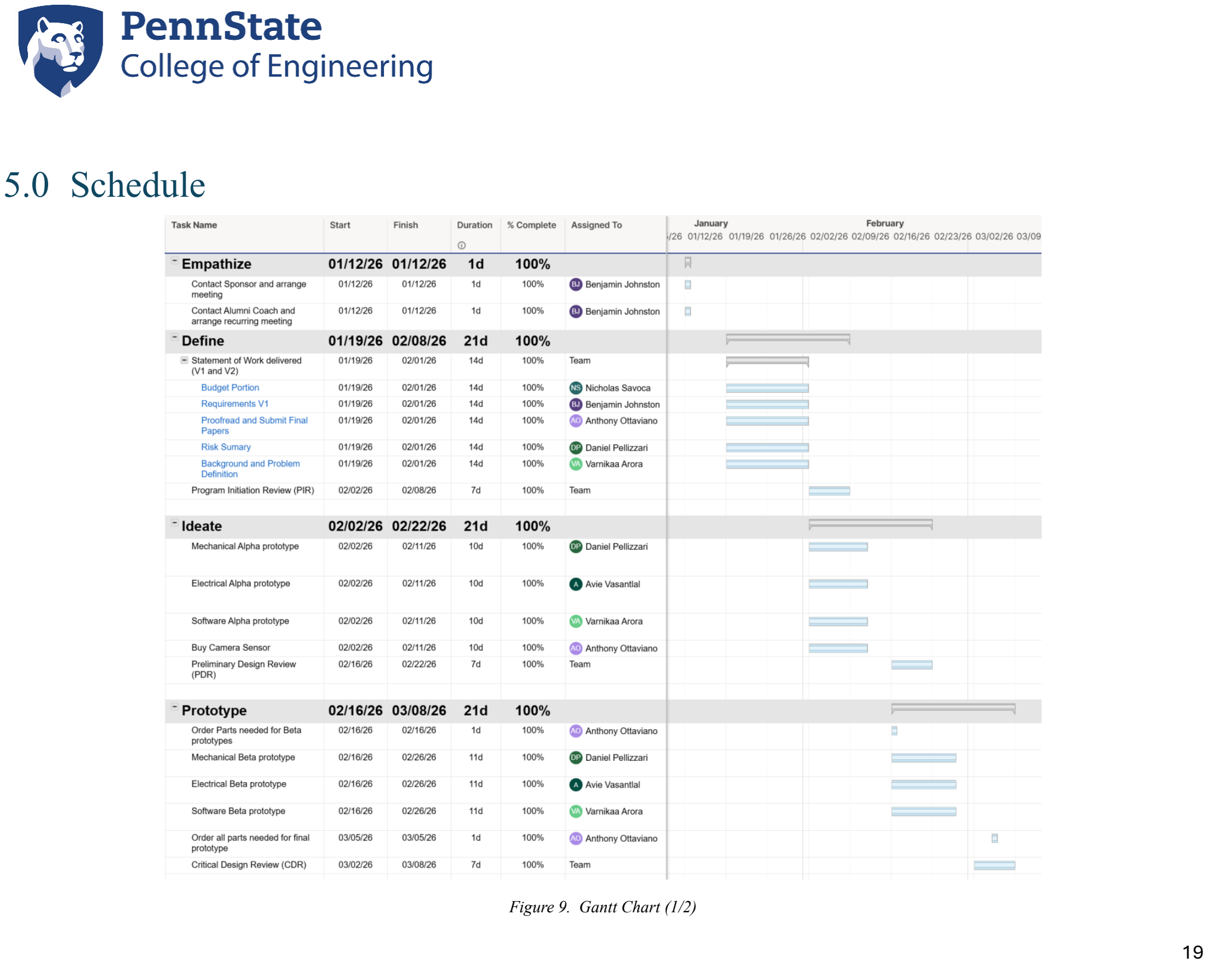
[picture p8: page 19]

19

Figure 9. Gantt Chart (1/2)

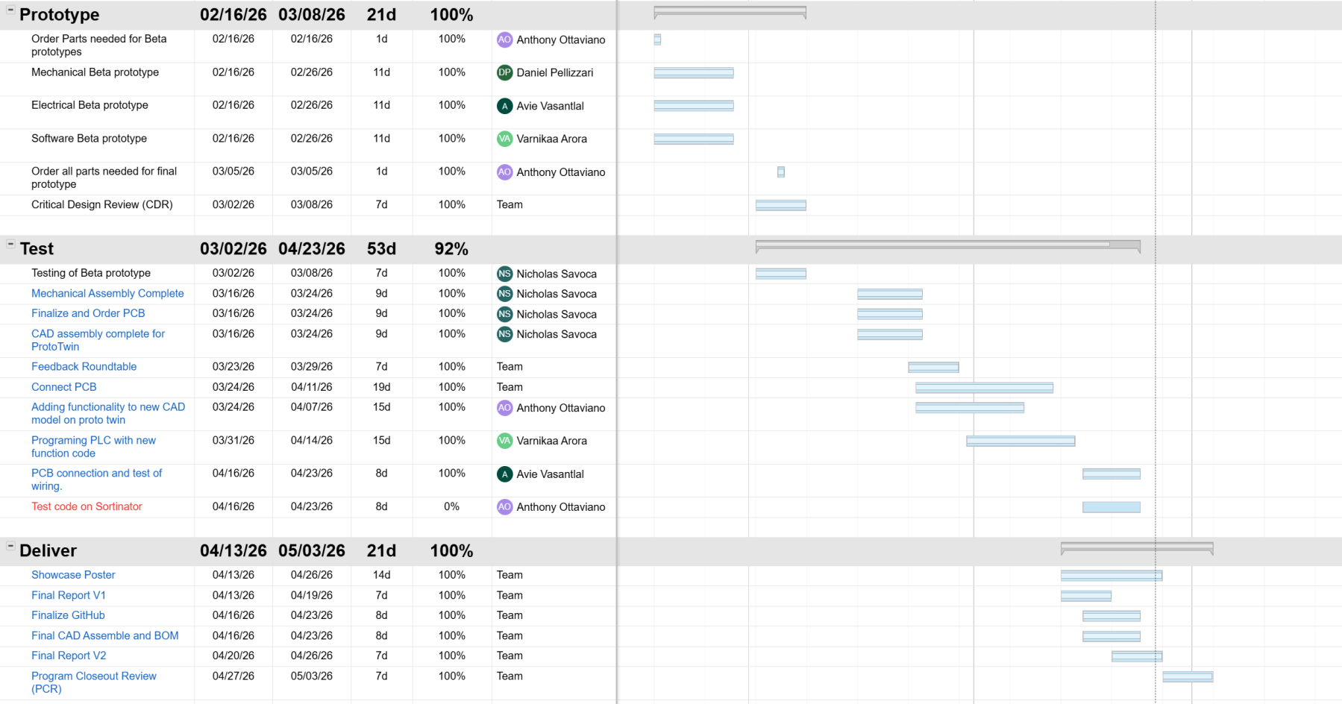
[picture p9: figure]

20

Figure 10. Gantt Chart (2/2)

# 6.0 Results

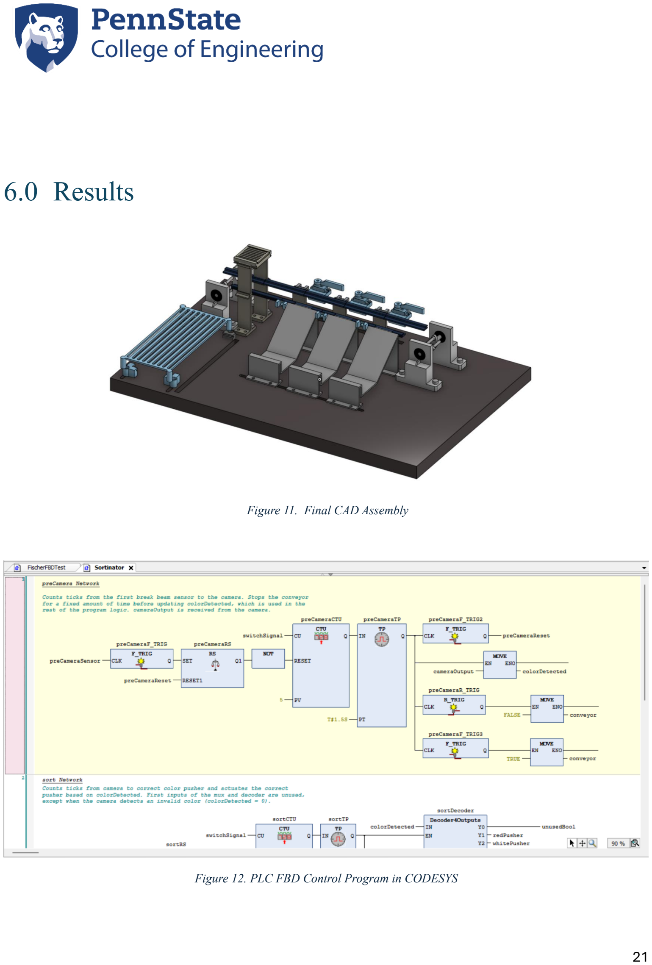
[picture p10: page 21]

Figure 11. Final CAD Assembly

Figure 12. PLC FBD Control Program in CODESYS

For the PLC, we developed a control program in function block diagram. This program should be helpful for students to understand how to program in this language to automate industrial machines and processes.

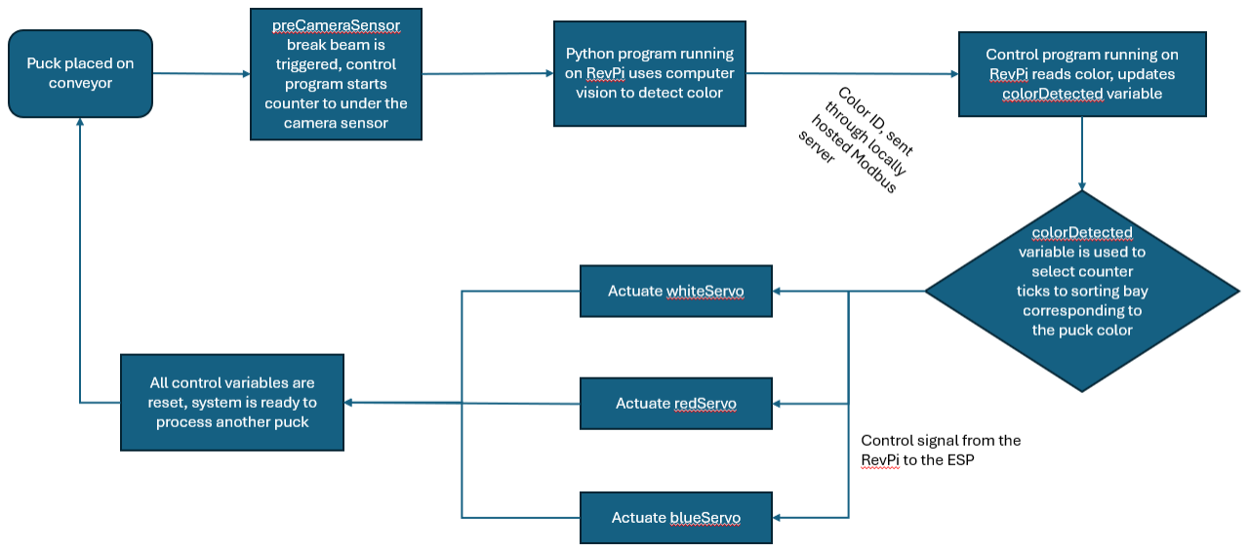
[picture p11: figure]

Figure 13. High-level Control System Flowchart

The above diagram illustrates the control system of the Sortinator at a high level. First, a puck is placed in the conveyor. Then, when the puck triggers the first break beam sensor before the camera, the control program begins a counter that uses the microswitch to track how far the puck has moved. Then, the puck is stopped under the camera module, and a Python program running on the RevPi (RevolutionPi, 2025) uses the input from the camera and computer vision to detect the color. The program then sends the ID of the color detected to the RevPi (RevolutionPi, 2025) through a locally hosted Modbus server. The colorDetected variable is updated based on the color read, which is used to determine which servo is actuated. Then, after the counter determines that a puck is in front of the correct sorting bay, a control signal is sent out from the RevPi (RevolutionPi, 2025) to actuate the correct servo. Lastly, all control variables are reset, readying the system to process another puck.

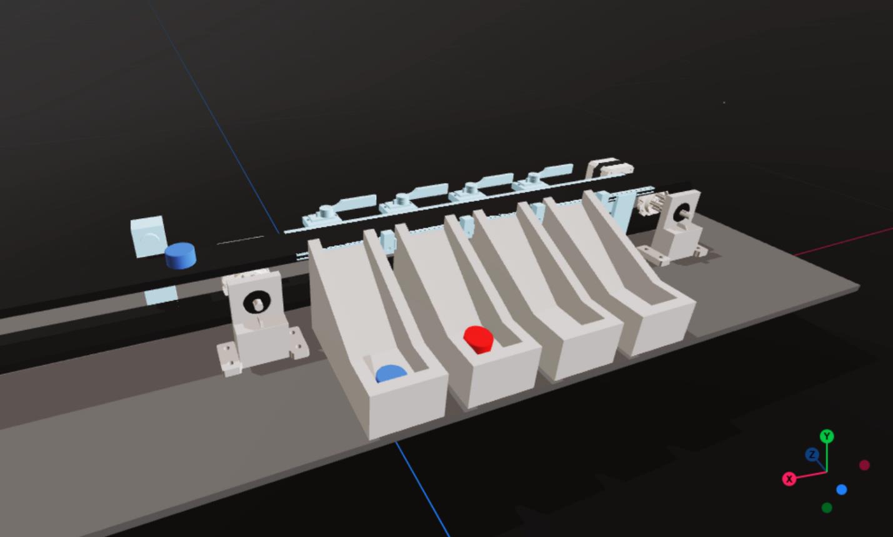
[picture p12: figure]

Figure 14. Screenshot of ProtoTwin Simulation

The ProtoTwin simulation (ProtoTwin, 2025) provides a virtual simulation of the Sortinator. This virtual simulation was somewhat helpful in assisting the software team in their development of the control logic of the Sortinator without a physical prototype. Though ProtoTwin (ProtoTwin, 2025) can be a powerful resource for providing a simulation for testing control logic if set up correctly, adding precise physics and functionality to the CAD models is a time-consuming process, lessening the usefulness of this software for rapid prototyping; for this reason, the simulation differs from the physical prototype in a few key areas. For example, our simulation does not stop the conveyor to read the color, nor does it simulate the microswitch for counting ticks on the conveyor. Due to these differences, in porting the code from the ProtoTwin (ProtoTwin, 2025) to the Sortinator, additional control logic had to be added to address the additional constraints present in the physical model. For those looking to further develop or modify the Sortinator design, this simulation can be used to rapidly test different control logic or mechanical designs without the need for development of a physical prototype, so long as the simulation is modified to more precisely reflect the physical model.

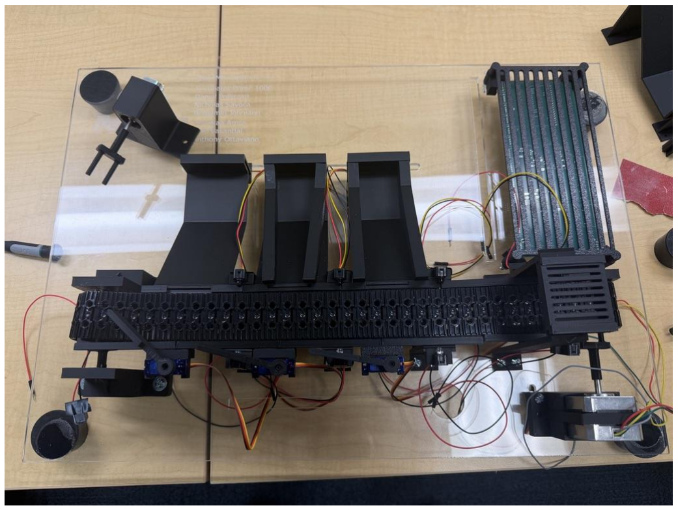
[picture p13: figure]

Figure 15. Mechanical Assembly

The final mechanical protype was mounted on an acrylic baseplate which was laser cut and engraved allowing each part to be mounted precisely without any major adjustments. It also features cut out slits for wire management, allowing wires to be out of the way and at no risk of interfering with the conveyor belt. Furthermore, sensitive electronic components such as the PCBA and camera are protected by printed cases.

## 6.1 Requirements Verification

The Verification Cross-Reference Matrix (VCRM) helps to organize and summarize which requirements have been met by our project, and which have not. There are three potential options, Pass, Fail, or Partial. The chart includes the methods for testing, the success criteria, and the specific result when applicable.

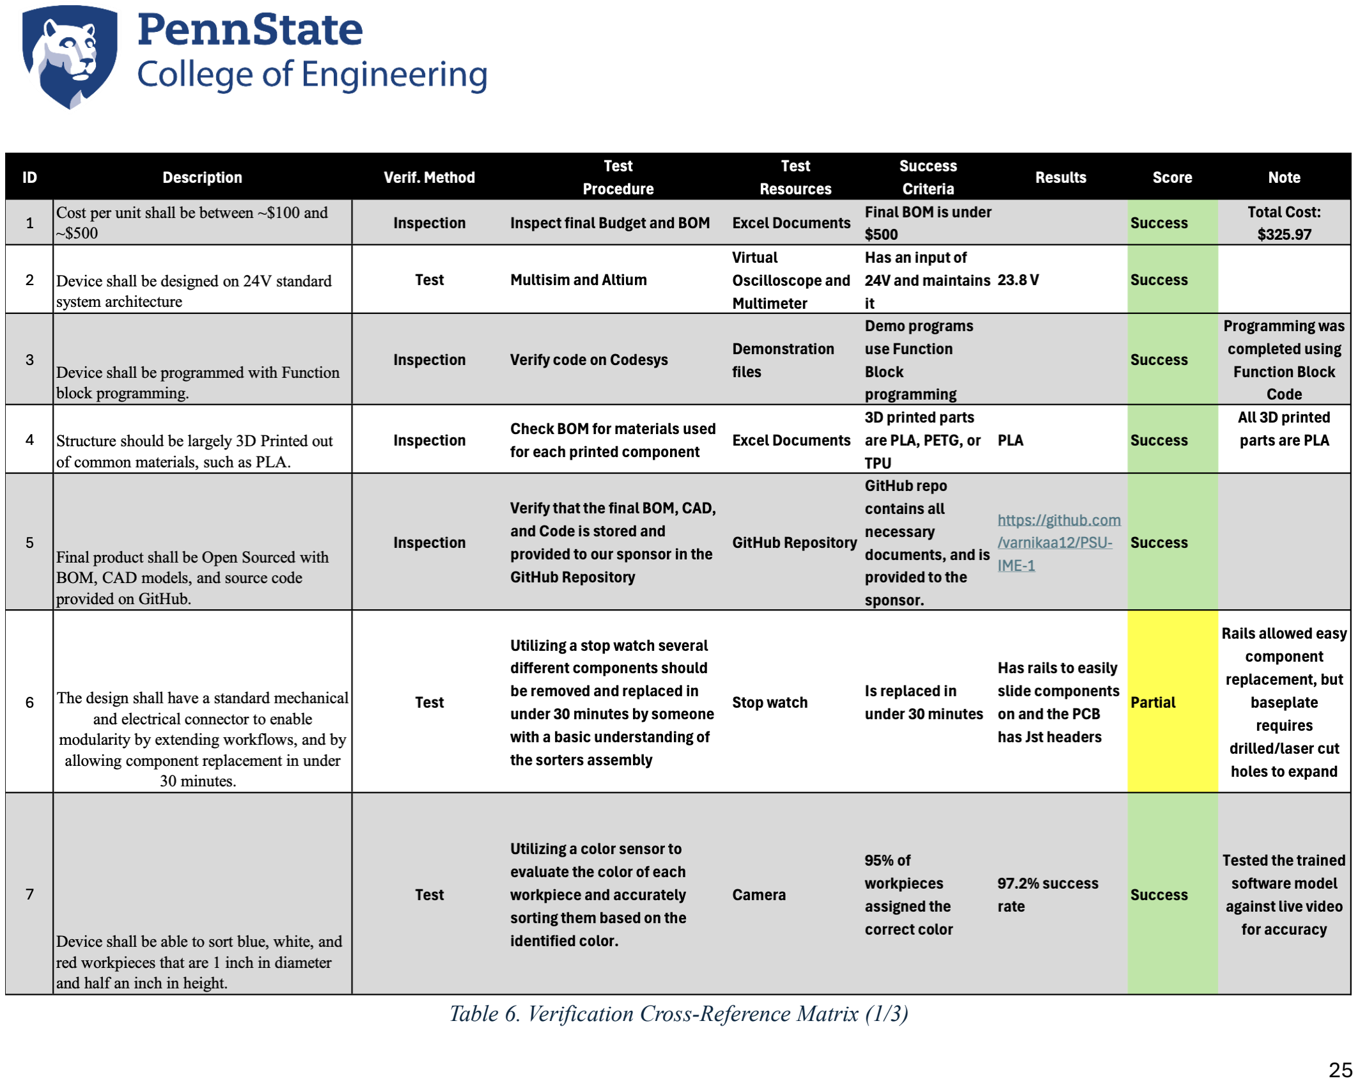
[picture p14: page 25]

25

Table 6. Verification Cross-Reference Matrix (1/3)

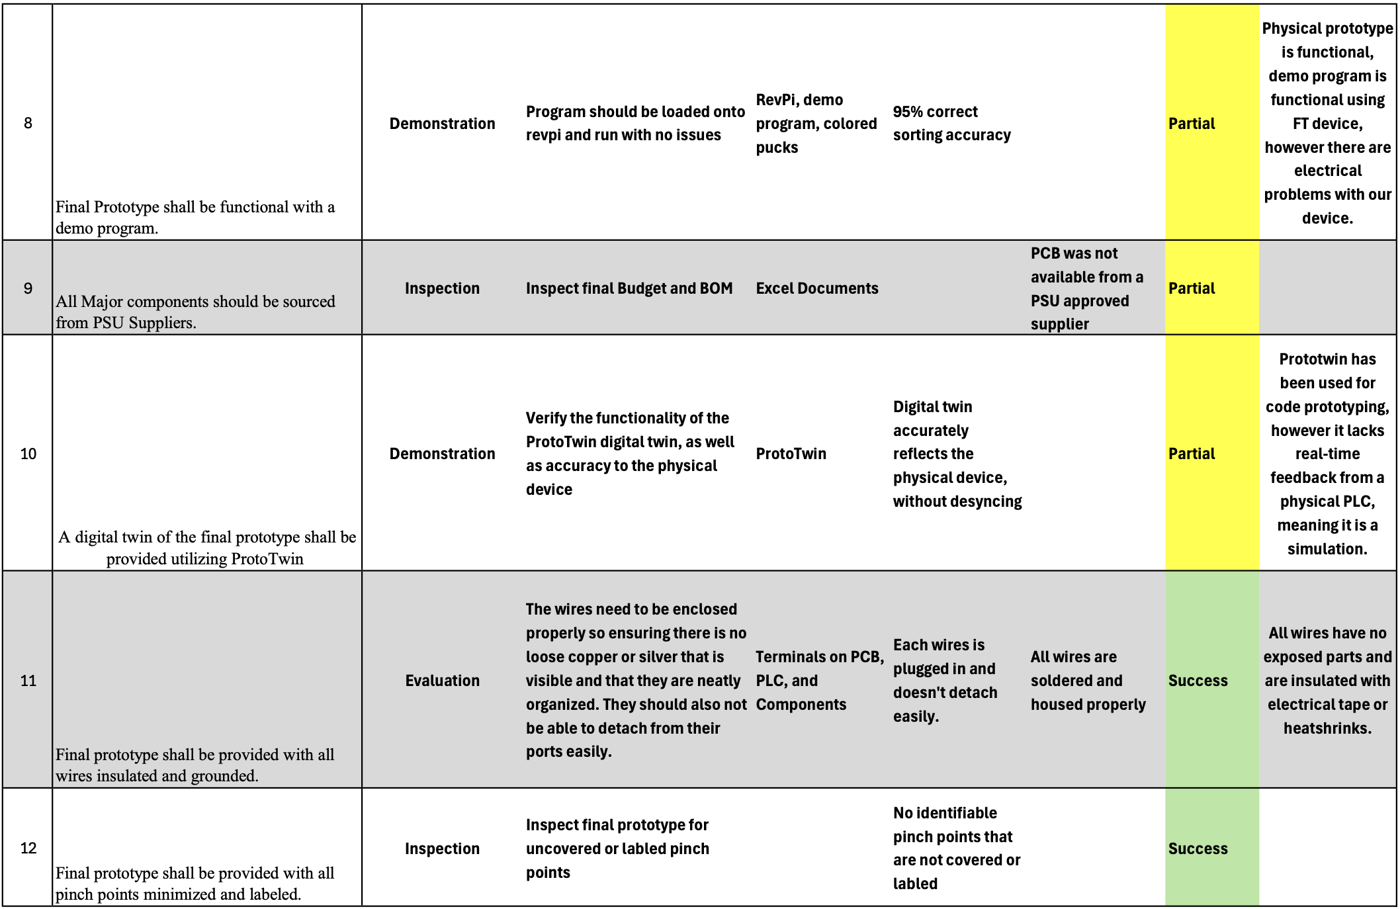
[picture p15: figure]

26

Table 7. Verification Cross-Reference Matrix (2/3) | dw

27

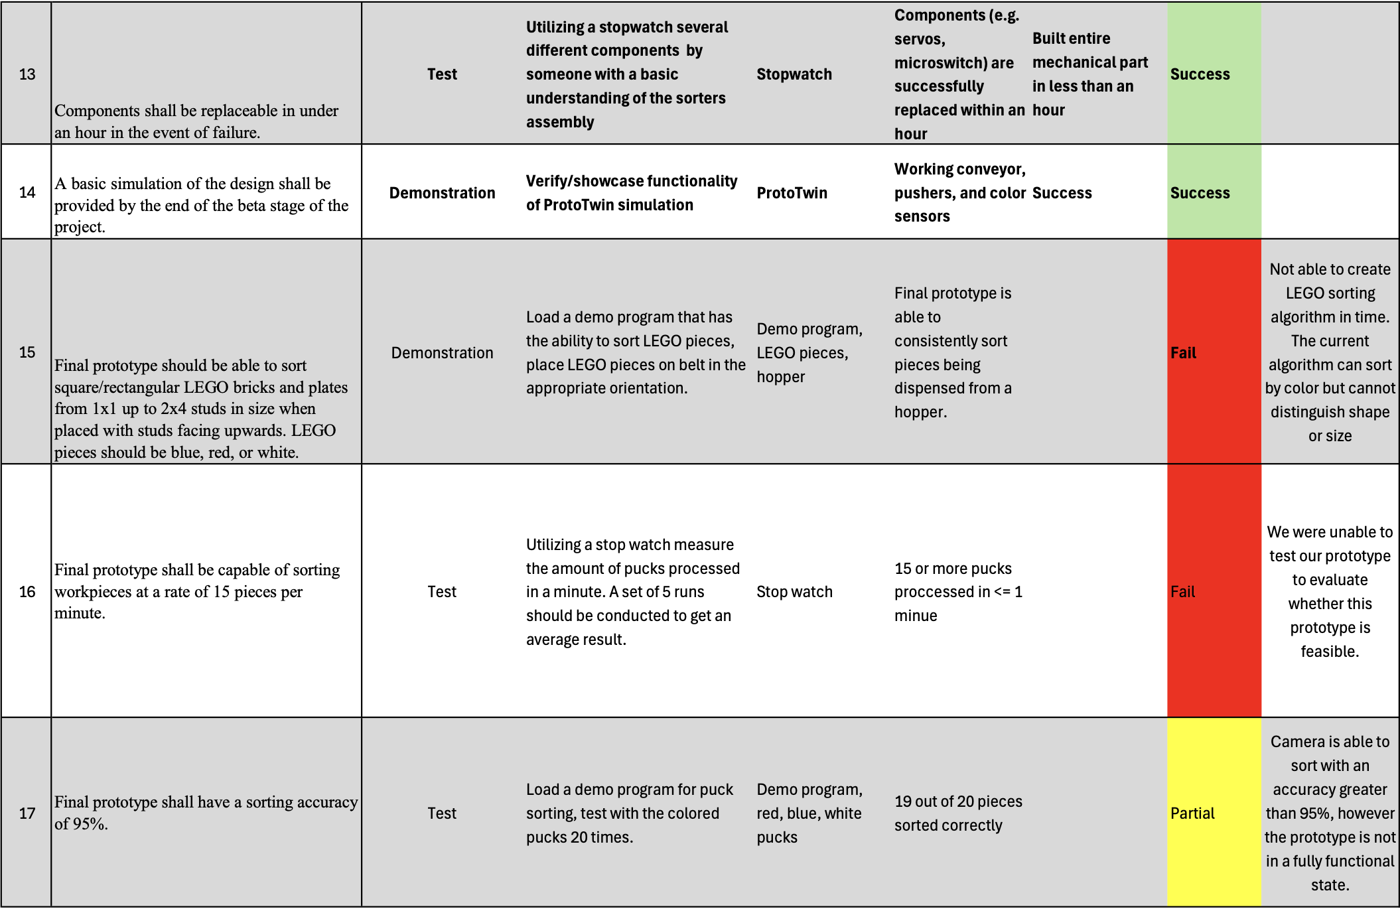
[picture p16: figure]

Table 8. Verification Cross-Reference Matrix (3/4)

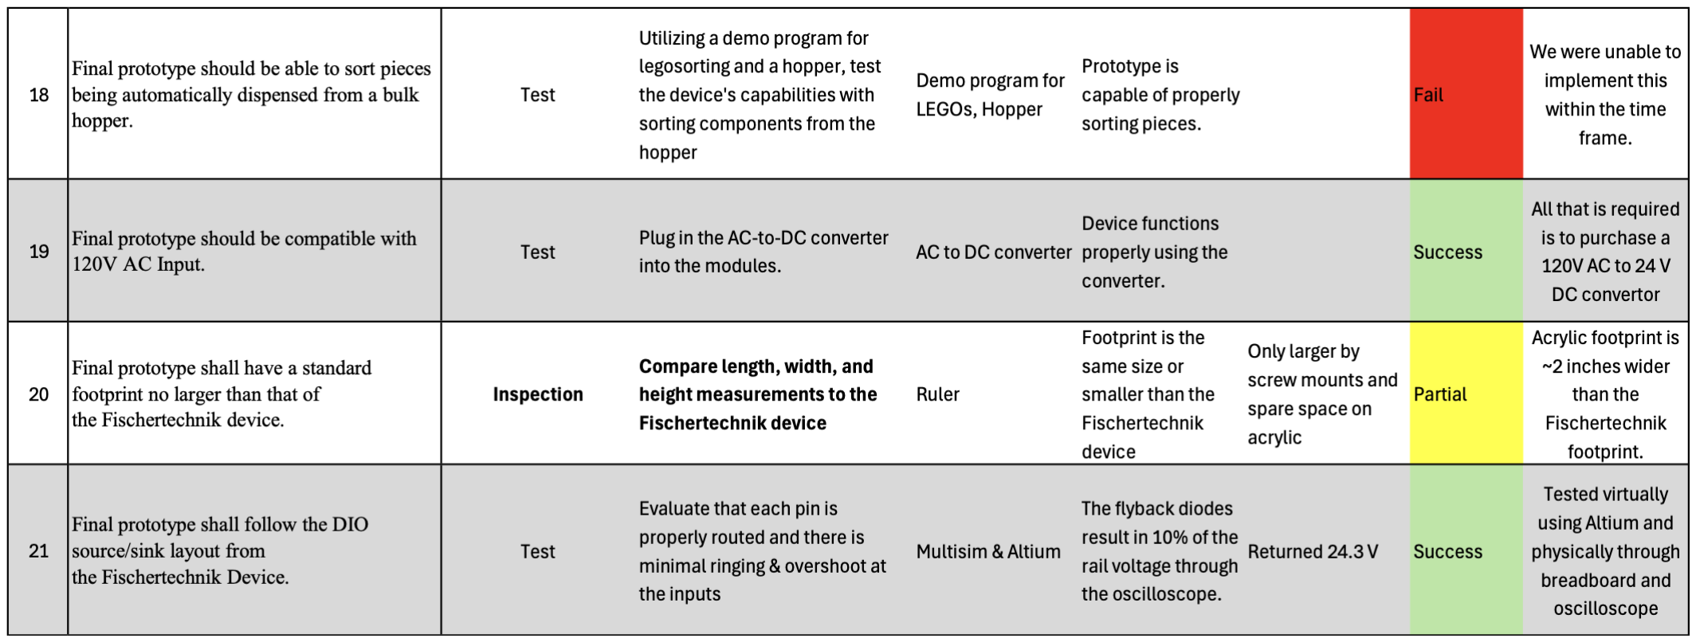
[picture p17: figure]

28

Table 9. Verification Cross-Reference Matrix (4/4)

As shown above in the chart above, there are a total of 3 requirements that are not met by the project. The first of which being the capability to sort some types of LEGO pieces with computer vision. We were unable to implement this requirement in time, this was a stretch goal, and the ability to sort the pucks was prioritized. The second requirement that we were unable to meet was the ability to process 15 or more pucks in a minute. This limitation is due in part to the time it takes to process each puck’s color, but primarily due to the control logic of the PLC only allowing one puck to be processed at a time. This means that if the camera detects another puck, it will overwrite the logic of the existing color, even if the previous puck hasn’t been processed yet. The third requirement that we were unable to meet was using a hopper to dispense pucks. This is another stretch goal, the current device requires the user to place the pucks by hand, and this would have automated this step. We were unable implement this in time, as the team was focused on achieving the core requirements first.

Overall, most requirements have been met, and with future work, the remaining few could likely be met as well.

## 6.2 Deliverables

Table 10. Deliverables table

ID | Description | Type | Planned Date

Actual
Date

Delivery
Method
1 | Final Prototype | Physical | 4/26/26 | 4/28/26 | Showcase Hand-off
2 | Bill of Materials | Digital | 4/26/26 | 4/26/26 | Final Report (Appendices B and C)
3 | CAD Model | Digital | 4/26/26 | 4/28/26 | GitHub (link) (https://github.com/varnikaa12/PSU-IME-1)
4 | Source Code (CODESYS project, Python camera program, ESP code) | Digital | 4/26/26 | 4/28/26 | GitHub
5 | Wiring Diagram | Digital | 4/26/26 | 4/28/26 | GitHub
6 | ProtoTwin Simulation | Digital | 4/26/26 | 4/28/26 | GitHub
7 | Assembly Drawings | Digital | 4/26/26 | Not Achieved | -
All deliverables have been delivered on time, except the stretch goal of assembly drawings of the final prototype.

## 6.3 Future Work

Though we completed the simulation of the Sortinator in ProtoTwin (ProtoTwin, 2025), we failed to meet the stretch goal of having a true digital twin. The software team planned to finish the digital twin aspect of the ProtoTwin (ProtoTwin, 2025) after making a successful physical prototype. However, we did not anticipate the possibility of shipping delays that made us unable to test on the physical prototype when we wanted to. If we wanted to have a digital twin, we should have switched focus to further development of the ProtoTwin (ProtoTwin, 2025) despite the delays in creating the physical prototype.

Another stretch goal we did not meet within the given timeframe was enabling the Sortinator to sort square and rectangular LEGO bricks that are automatically dispensed from a bulk hopper. In order to implement this in the future, the mechanical design must be expanded to include extra ramps specifically tailored to the LEGO dimensions, along with the creation and integration of the hopper. Also, we believe our requirement to process 15 pieces per minute would not be met due to the latency required to detect and transport each puck down the line, but we did not have a chance to test it to know for certain. Future development can go to optimizing our color-detecting Random Forest classification model, which is in the GitHub repository, to reduce color detection time.

A few hardware and documentation requirements need more progress to fully satisfy the original project scope. The current system is incompatible with a 120V AC input, which means that the future versions should integrate an AC-to-DC converter module to run properly. We also noted that the system’s footprint is slightly larger than the Fischertechnik device (fischertechnik, 2016) due to screw mounts and spare acrylic board space, and the PCB had to be sources outside of approved PSU suppliers. Going forward, the mechanical footprint can be optimized, and all final CAD models, BOMs, and source code must be fully organized and published to the GitHub repository to complete the open-source aspect of the project and for us to be able to hand it over to our sponsor.

## 6.4 Expected Benefits

The Sortinator improves upon the original Fischertechnik sorting line (fischertechnik, 2016) by prioritizing affordability, accessibility, and expandability. The most substantial benefit of this project is its financial impact; we sourced cost-effective industrial components and reduced the cost per unit to $325.97. Compared to the commercial equivalent, which retails for approximately $1,387 (Studica, n.d.), which is a cost reduction of 76.498%. This decrease in cost greatly increases the affordability of this educational tool, making industrial automation training accessible to a broader range of academic institutions.

This solution is unique because of its commitment to an open-source, highly modular architecture. All the materials, schematics, and software associated with the Sortinator are entirely free and open source. The physical prototype was intentionally designed with modularity in mind, allowing anyone to build their own version of the tool, and giving them the option to modify, upgrade, and build upon our baseline based on their needs.

To make sure the system’s longevity and scalability, all the project documentation is centrally hosted on GitHub. Our repository will include general instructions on how how to build a complete Sortinator, along with the necessary CAD, BOM, etc files. This level of detailed documentation has benefits such as making it very easy for institutions to manufacture and deploy multiple units for classroom or testing purposes and drastically lowering the barrier to entry for future developers, ensuring that adding new features, sensors, or software integrations would be a straightforward process.

This project greatly improves the affordability and modularity of the original Fischertechnik design (fischertechnik, 2016), providing an effective, adaptable tool to teach students how to program PLCs and automate industrial machines and processes.

# 7.0 Expenditures

There was a large difference in what we believed our cost would be compared to what we actually spent. The main differences between actual expenditures and proposed expenditures can be explained by express shipping costs from later in the semester. For example, under “PCBs”, we ended up spending $360.99 more than anticipated. This was because we were limited to U.S.-based PSU-recommended suppliers, which were much more expensive than other manufacturers. Additionally, for each set of 3 PCBs, express shipping cost nearly $100 for each order. For “Integrated Circuits and PCB Components”, we ended up spending $197.57 more than anticipated, mainly due to express shipping costs as well. Because reimbursements have not yet been sent out, the budget in Appendix A may be slightly more than the actual final budget. Receipts for some orders have not yet been received for orders from the Learning Factory. In these cases, we have added together listed prices of each item in the order. Because of Penn State’s partnership with suppliers, these cost estimates of these orders are overestimates of the actual costs of these orders.

# Acknowledgements

We would like to extend our gratitude to the individuals whose guidance, expertise, and support were instrumental in the progress of our sorting system capstone project.

First and foremost, we would like to thank our Sponsor, Advisor, and Professor, Brian Zajac, for conceptualizing this project and guiding us through its development. He has a passion for the subject matter and knowledge of industry practices. We appreciate his open-door policy and all the insightful feedback and direction he provided during our weekly meetings, from the initial design phases through to our final execution.

We are also extremely grateful to Elijah Gruver, whose technical assistance was indispensable. Elijah provided us with ladder logic code that served as a critical foundation for our software architecture. Also, he provided us with documentation for setting up the Revolution Pi and Fischertechnik tool (fischertechnik, 2016), along with his patience in answering our many questions, which accelerated our timeline. This project would not have reached its current level of success without their dedication and hands-on assistance.

Additionally, we would like to thank our Alumni Coach, Taylor Joseph, for providing ongoing mentorship and industry perspective as a recent graduate who also went through the whole capstone program, along with Danielle Snyder for her assistance in ordering parts through Penn State.

# References

ABB. (n.d.). Overview of the IEC 61131 standard [Data sheet 2101127-AB]. https://library.e.abb.com/public/81478a314e1386d1c1257b1a005b0fc0/2101127.pdf

CODESYS GmbH. (2026). CODESYS Development System (Version X.X) [Computer software]. Kempten, Germany. CODESYS Official Site.

fischertechnik. (2025, December). plc_training_factory_24v: Training Factory Industry 4.0 (24V) [Source code]. GitHub. https://github.com/fischertechnik/plc_training_factory_24v

fischertechnik. (2016, January). Sorting Line with Color Detection 24V [Product page]. fischertechnik. https://www.fischertechnik.de/en/products/industry-and-universities/training-models/536633-sorting-line-with-color-detection-24v[VA23.1]

fischertechnik. (n.d.-a). TDB_536633-SORTIERSTRECKE_MIT_FARBERKENNUNG_24V [Technical datasheet].
https://fiproductmedia.azureedge.net/media/Certification%20Documents/Technical%20Datasheets/fischertechnik/TDB_536633-
SORTIERSTRECKE_MIT_FARBERKENNUNG_24V.pdf[VA24.1]

OpenPLC. (2025). OpenPLC Editor and runtime documentation. GitHub. https://github.com/thiagoralves/OpenPLC_Editor[VA25.1]

ProtoTwin. (2025). ProtoTwin digital twin platform documentation. https://prototwin.com/docs

[VA26.1]RevolutionPi. (2025). RevPi DIO, AIO, and Core SE technical documentation. GitLab. https://gitlab.com/revolutionpi/

Studica. (n.d.). fischertechnik Sorting Line with Color Detection 24V [Product page]. https://www.studica.com/sorting-line [VA27.1]

# Appendix A: Budget

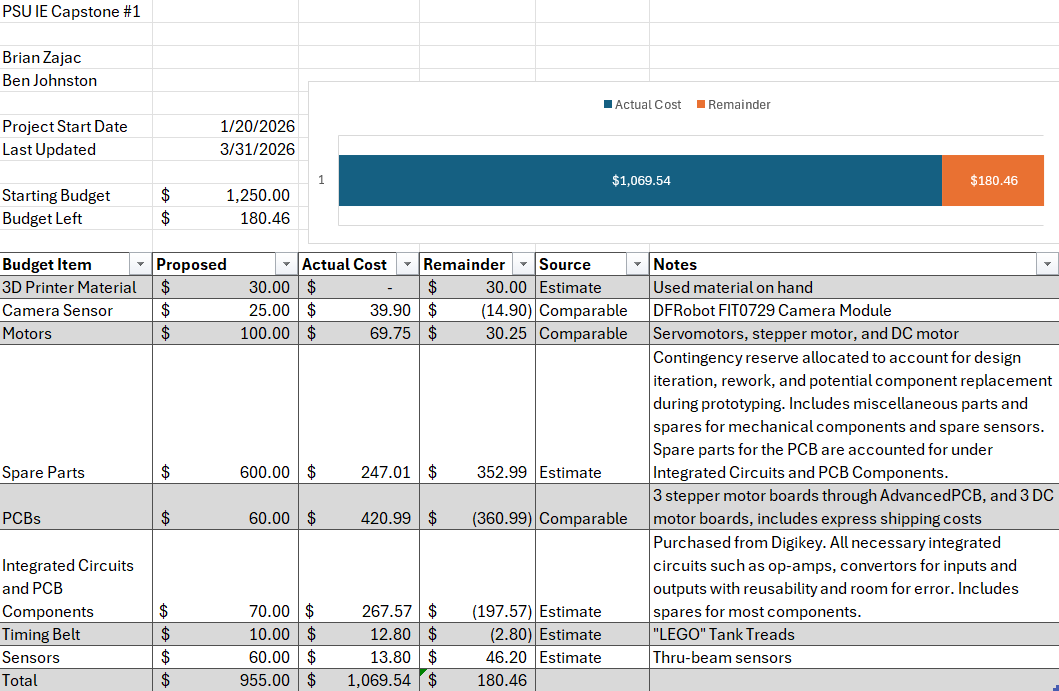
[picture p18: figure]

Figure 26. Final Budget

# Appendix B: CAD Models

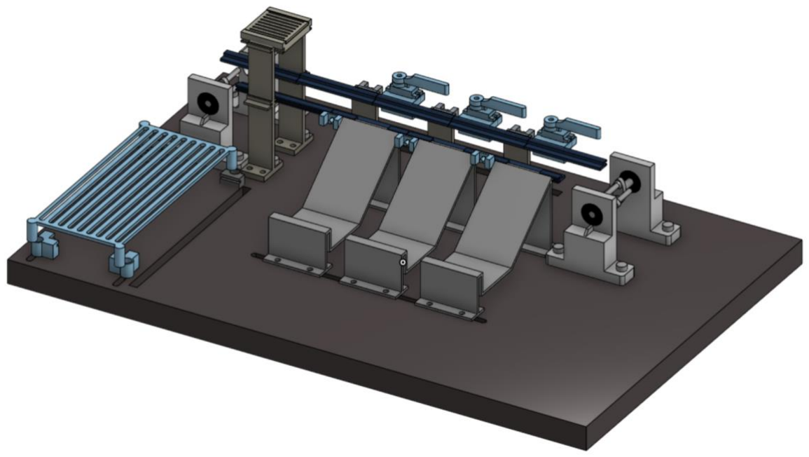
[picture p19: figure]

Figure 37. Final CAD Model

Final CAD Assembly, for visibility, the belt is not modeled, the PCB would be mounted on the bottom left side of the baseplate. Pucks would flow from left to right along the belt and then are derailed by the lever arms attached to the servos.

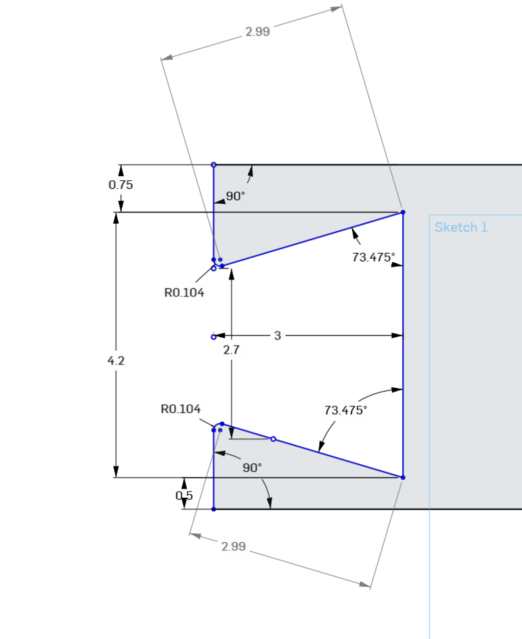
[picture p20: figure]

Figure 48. Rail Connector Sketch

Figure 18 shows a 2D sketch of the rail connector. This is how the rails would slide onto the legs and the break beam mounts slide into the slot as well.

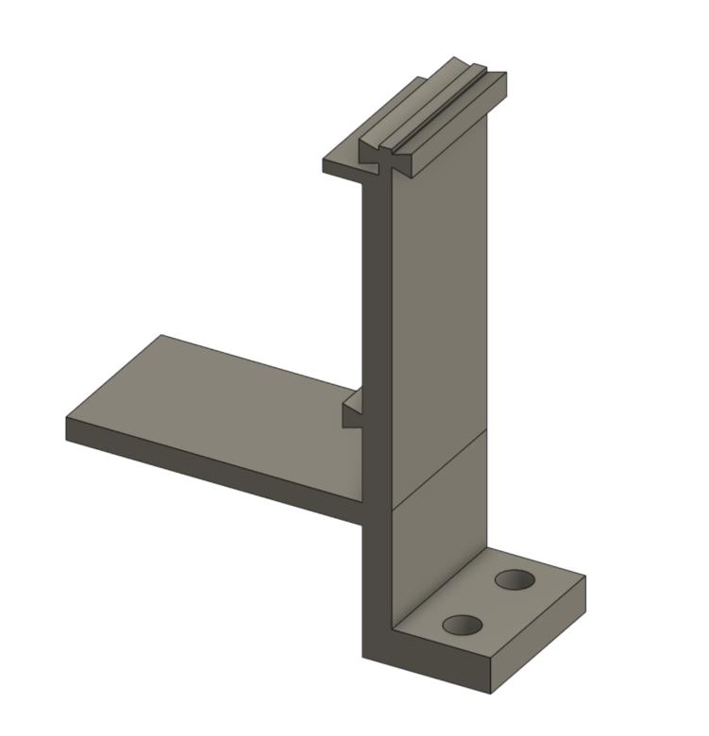
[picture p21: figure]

Figure 59. Final leg design

Figure 19 shows the final leg design that was used in the final prototype. There are several additions when compared to the legs from the beta prototype. There is a rear-facing connector that is meant to mount the break beams. There is also a lower rail connector that is how the microswitch is mounted to the frame. Finally, there is a ledge for the belt to rest on and prevent sagging, this also helps to ensure the microswitch can trigger.

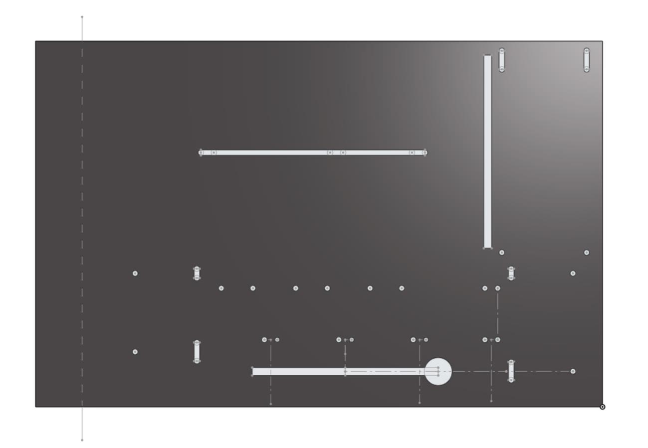
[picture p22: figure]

Figure 20. Final Baseplate design for 3 bays

Figure 20 shows the final baseplate design for 3 bays. The PCB would be mounted in the top right from this orientation, and motor would be mounted on the bottom right. This baseplate was made from 0.25 in thick acrylic that was laser cut with this pattern.

# Appendix C: Main BOM

Quantity | Cost per Unit | Total | Item Description | Links
1 | 94.71 | 94.71 | PCB Components (For 1 board, look at PCB Parts List for more detail) | (See PCB Parts List)
1 | 33 | 33 | PCB (1 board) | AdvancedPCB Link (https://www.my4pcb.com/Net/Promotion/OrderFileUpload)
1 | 14 | 14 | Stepper Motor | Digikey Link (https://www.digikey.com/en/products/detail/adafruit-industries-llc/324/5022791)
3 | 5.95 | 17.85 | Servos (3) | Digikey Link (https://www.digikey.com/en/products/detail/adafruit-industries-llc/169/5154651)
4 | 6.9 | 27.6 | Through Beam (4) | Digikey Link (https://www.digikey.com/en/products/detail/adafruit-industries-llc/2168/8258463)
1 | 39.9 | 39.9 | Camera Module | Digikey Link (https://www.digikey.com/en/products/detail/dfrobot/fit0729/13688349)
1 | 12.8 | 12.8 | Tank Treads (For the full set) | Amazon Link (https://www.amazon.com/108Pcs-Technical-Motorcycle-Accessories-Building/dp/B0BKFQPS5T?s=toys-and-games)
1 | 1.39 | 1.39 | Microswitch | Digikey Link (https://www.digikey.com/en/products/detail/omron-electronics-inc-emc-div/SS-5GL13T/31113)
3 | 0.98 | 2.94 | Bearings (3) | Bearings (https://www.digikey.com/en/products/detail/mechatronics-bearing-group/608-2RS-W-CHEVRONSRI2/9608369)
1 | 9.98 | 9.98 | Gorilla Clear Max Super Glue (most glues compatible)
1 | 6.98 | 6.98 | 26x #10-32 1-inch Bolts with Nuts (M5 also works)
1 | 6.98 | 6.98 | Washers
4 | 4.35 | 17.4 | 4x Rubber Feet (just needs to have a ~1 inch standoff)
3 | 1.55 | 4.65 | Ramp with sidewalls
2 | 0.06 | 0.12 | PCB Holder (Corner)
2 | 0.05 | 0.1 | PCB Holder (side)
1 | 0.61 | 0.61 | PCB Cover
1 | 0.06 | 0.06 | Microswitch Holder
1 | 0.1 | 0.1 | Long Rail
3 | 0.06 | 0.18 | Rail for Ramp
5 | 0.07 | 0.35 | Rail
3 | 0.07 | 0.21 | Bearing Side Adapter
1 | 0.07 | 0.07 | Motor Side Adapter (stepper)
1 | 0.57 | 0.57 | Stepper Motor Stand
1 | 0.08 | 0.08 | Motor Side Adapter (DC Motor)
1 | 0.59 | 0.59 | DC Motor Stand
1 | 0.06 | 0.06 | Camera Lid
1 | 0.14 | 0.14 | Camera Rail Mount
2 | 0.31 | 0.62 | Camera Mounting Leg
3 | 0.03 | 0.09 | Break Beam Mount (goes on rail)

3 | 0.03 | 0.09

## Break Beam Mount Inverse (goes on back of leg)

3 | 0.04 | 0.12 | Lever Arm
3 | 0.09 | 0.27 | Servo Holder
3 | 0.23 | 0.69 | Leg
1 | 29.32 | 29.32 | Acrylic Sheet (16 x 24 x 0.25 in)
3 | 0.45 | 1.35 | Bearing Mount
325.97 | TOTAL

# Appendix D: Electrical Final Schematic

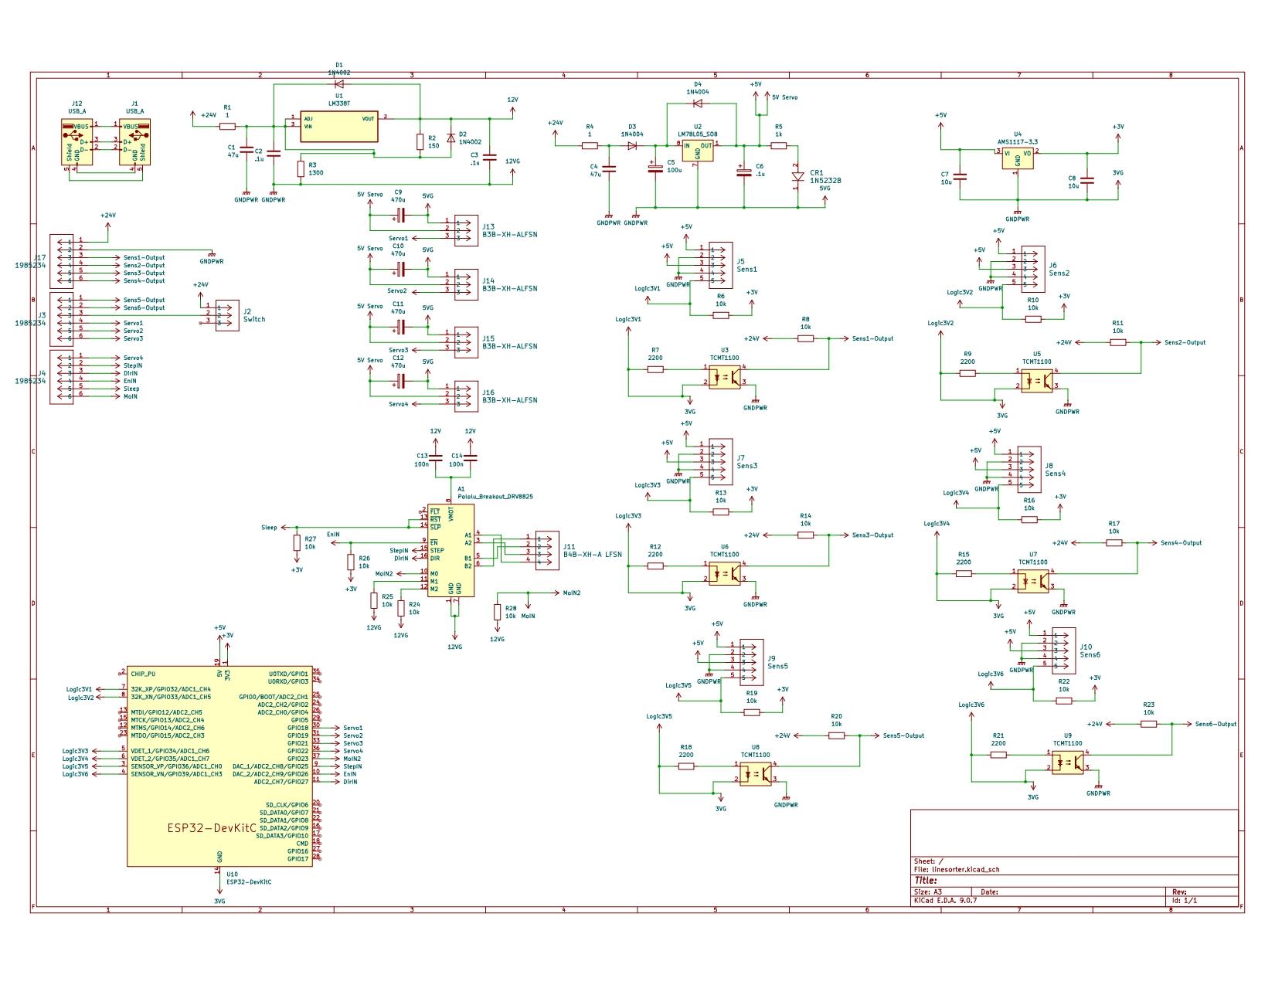
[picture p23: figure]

Figure 21. Final Schematic

This is the final electrical schematic for the line sorter. This was assembled in KiCad and utilized three different convertors consisting of 24 V to 12 V, 12 V to 5V and 5V to 3.3V. 12 volts were used to supply the stepper motor, 5 volts were used to supply the servos and the breakbeams and 3.3 V were used to supply the ESP32 with power. All signals are sent to interface with the ESP32 and can be controlled with either the RevPI, ESP32, or both concurrently. Optocouplers are used to allow signal transmission to the RevPi without facing damage due to interfacing with 24V power despite being powered by 5V.

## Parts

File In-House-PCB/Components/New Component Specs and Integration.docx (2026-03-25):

Target Components: 1x Stepper, 4x Servos, 1x IR Sensor, 1x USB Camera

1. Power Distribution and Regulation The PCB must handle two primary voltage rails. Total peak current is estimated at 3.5A.

12V Rail (Primary Input):

- Stepper Motor: 0.35A per phase

5V Rail (Regulated):

- 4x Hobby Servos: 500mA peak each (2A total)
- USB Camera: 260mA max
- IR Sensor: 20mA max

Engineer Note: Use a high-efficiency buck regulator for the 5V rail (min 3A rating) and include a 470uF electrolytic decoupling capacitor near the servo headers to handle transient spikes.

2. Component Interface Details

Hobby Servo (Adafruit 169): 4 units. Use male shrouded headers with 2.54mm (0.1 inch) pitch. Wiring: 1: Signal (Orange), 2: 5V (Red), 3: GND (Brown).

Stepper Motor (XY42STH34): 1 unit. Use JST-VH or Molex KK headers with 3.96mm pitch. Wiring: 1: Red (A), 2: Yellow (C), 3: Gray (B), 4: Green (D).

IR Break Beam (Adafruit 2168): 1 unit. Use male headers with 2.54mm (0.1 inch) pitch. Wiring: 1: 5V (Red), 2: GND (Black), 3: Signal (White).

USB Camera (DFRobot FIT0729): 1 unit. Use 4P-2.0mm header with 2.0mm pitch. Interfaces with USB Data plus/minus and 5V/GND.

3. Mandatory Protection and Logic IR Sensor Logic: The receiver is Open Collector. The PCB must include a 10K Pull-up Resistor between the Signal (White) and 5V (Red) lines.

Stepper Control: Include footprints for an A4988 or DRV8825 driver module to interface with the 4-lead motor.

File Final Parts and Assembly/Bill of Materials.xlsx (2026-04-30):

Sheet: Final BOM
Quantity | Cost per Unit | Total | Item Description | Links
1 | 94.71 | 94.71 | PCB Components (For 1 board, look at PCB Parts List for more detail) | (See PCB Parts List)
1 | 33 | 33 | PCB (1 board) | AdvancedPCB Link (https://www.my4pcb.com/Net/Promotion/OrderFileUpload)
1 | 14 | 14 | Stepper Motor | Digikey Link (https://www.digikey.com/en/products/detail/adafruit-industries-llc/324/5022791)
3 | 5.95 | 17.85 | Servos (3) | Digikey Link (https://www.digikey.com/en/products/detail/adafruit-industries-llc/169/5154651)
4 | 6.9 | 27.6 | Through Beam (4) | Digikey Link (https://www.digikey.com/en/products/detail/adafruit-industries-llc/2168/8258463)
1 | 39.9 | 39.9 | Camera Module | Digikey Link (https://www.digikey.com/en/products/detail/dfrobot/fit0729/13688349)
1 | 12.8 | 12.8 | Tank Treads (For the full set) | Amazon Link (https://www.amazon.com/108Pcs-Technical-Motorcycle-Accessories-Building/dp/B0BKFQPS5T?s=toys-and-games)
1 | 1.39 | 1.39 | Microswitch | Digikey Link (https://www.digikey.com/en/products/detail/omron-electronics-inc-emc-div/SS-5GL13T/31113)
3 | 0.98 | 2.94 | Bearings (3) | Bearings (https://www.digikey.com/en/products/detail/mechatronics-bearing-group/608-2RS-W-CHEVRONSRI2/9608369)
1 | 9.98 | 9.98 | Gorilla Clear Max Super Glue (most glues compatible)
1 | 6.98 | 6.98 | 26x #10-32 1-inch Bolts with Nuts and Bolts (M5 size also compatible)
1 | 6.98 | 6.98 | Washers
4 | 4.35 | 17.4 | 4x Rubber Feet (does not need to be a specific part, just needs to provide ~1 inch of standoff)
3 | 1.55 | 4.65 | Ramp with sidewalls
2 | 0.06 | 0.12 | PCB Holder (Corner)
2 | 0.05 | 0.1 | PCB Holder (side)
1 | 0.61 | 0.61 | PCB Cover
1 | 0.06 | 0.06 | Microswitch Holder
1 | 0.1 | 0.1 | Long Rail
3 | 0.06 | 0.18 | Rail for Ramp
5 | 0.07 | 0.35 | Rail
3 | 0.07 | 0.21 | Bearing Side Adapter
1 | 0.07 | 0.07 | Motor Side Adapter (stepper)
1 | 0.57 | 0.57 | Stepper Motor Stand
1 | 0.08 | 0.08 | Motor Side Adapter (DC Motor)
1 | 0.59 | 0.59 | DC Motor Stand
1 | 0.06 | 0.06 | Camera Lid
1 | 0.14 | 0.14 | Camera Rail Mount
2 | 0.31 | 0.62 | Camera Mounting Leg
3 | 0.03 | 0.09 | Break Beam Mount (goes on rail)
3 | 0.03 | 0.09 | Break Beam Mount Inverse (goes on back of leg)
3 | 0.04 | 0.12 | Lever Arm
3 | 0.09 | 0.27 | Servo Holder
3 | 0.23 | 0.69 | Leg
1 | 29.32 | 29.32 | Acrylic Sheet (16 x 24 x 0.25 in)
3 | 0.45 | 1.35 | Bearing Mount
 |  | 325.97 | TOTAL

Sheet: PCB BOM
Item | Quantity | Digikey | Mouser | Cost | Total | Notes
plc headers | 3 | https://www.digikey.com/en/products/detail/phoenix-contact/1985234/568663?curr=usd | https://www.mouser.com/ProductDetail/Phoenix-Contact/1985234?qs=A%2FKWGUWTCZgjCof%252B1YY92w%3D%3D | 1.19 | 3.57
3-terminal | 5 | https://www.digikey.com/en/products/detail/jst-sales-america-inc/B3B-XH-AM/1651029 | https://www.mouser.com/ProductDetail/JST-Commercial/B3B-XH-AMLFSN?qs=cdbOS8ANM9B1j44d7kpaHQ%3D%3D | 0.12 | 0.6 |  |  | https://tlcelectronics.com/tlc-1749.html
Stepper motor | 1 | https://www.digikey.com/en/products/detail/pololu/2987/10450470 | https://www.pololu.com/product/2987 | 16.95 | 16.95 |  | https://www.digikey.com/en/products/detail/pololu/2982/10450467
buck convertor | 1 | https://www.digikey.com/en/products/detail/texas-instruments/LM338T-NOPB/212669 | https://www.mouser.com/ProductDetail/Texas-Instruments/LM338T-NOPB?qs=X1J7HmVL2ZENaH7%2FMvkSlw%3D%3D | 2.4 | 2.4
TCMT1100 (optocouplers) | 6 | https://www.digikey.com/en/products/detail/vishay-semiconductor-opto-division/TCMT1100/1738630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 | https://www.mouser.com/ProductDetail/Vishay-Semiconductors/TCMT1100?qs=iFB%2FIts7N%252BB%2F3GkRaSvByw%3D%3D | 0.6 | 3.6
5 terminal | 6 | https://www.digikey.com/en/products/detail/jst-sales-america-inc/S5B-PH-K-S/926629 | https://www.mouser.com/ProductDetail/JST-Commercial/S5B-PH-K-SLFSN?qs=cdbOS8ANM9BOhIq9dvlRZA%3D%3D | 0.22 | 1.32
convertor | 1 | https://www.digikey.com/en/products/detail/texas-instruments/LM78L05ACZ-NOPB/6333 | https://www.mouser.com/ProductDetail/Texas-Instruments/LM78L05ACZ-NOPB?qs=QbsRYf82W3H4YoemQv80Cg%3D%3D | 0.63 | 0.63
USB-A | 2 | https://www.digikey.com/en/products/detail/on-shore-technology-inc/USB-A1VSB6/2677749 | https://www.mouser.com/ProductDetail/Same-Sky/UJ2-AV-2-TH?qs=5mqXD9RfOg11MgnPL0cI2A%3D%3D | 0.44 | 0.88
1n4004 diode | 2 | https://www.digikey.com/en/products/detail/diotec-semiconductor/1N4004/13164524 | https://www.mouser.com/ProductDetail/Diotec-Semiconductor/1N4004?qs=OlC7AqGiEDk3eaZusDVIWQ%3D%3D | 0.1 | 0.2
zener diode | 1 | https://www.digikey.com/en/products/detail/onsemi/1N5232BTR/458814 | https://www.mouser.com/ProductDetail/onsemi/1N5232BTR?qs=DGF5YW3GH8v76EPDJz%252BMgQ%3D%3D | 0.2 | 0.2
4 terminal | 1 | https://www.digikey.com/en/products/detail/jst-sales-america-inc/B4B-XH-A/1651047 | https://www.mouser.com/ProductDetail/JST-Commercial/B4B-XH-ALFSN?qs=cdbOS8ANM9CfC08d%252BywhFw%3D%3D | 0.16 | 0.16
ESP32 | 1 | https://www.digikey.com/en/products/detail/espressif-systems/ESP32-DEVKITC-32UE/12091813 | https://www.mouser.com/ProductDetail/Espressif-Systems/ESP32-DevKitC-32UE?qs=GedFDFLaBXFguOYDKoZ3jA%3D%3D | 8.08 | 8.08
1n-4002 | 2 | https://www.digikey.com/en/products/detail/diodes-incorporated/1N4002G-T/128571 | https://www.mouser.com/ProductDetail/Diodes-Incorporated/1N4002G-T?qs=rGAXPo9uwV1qqxEKGMICEQ%3D%3D | 0.24 | 0.48
https://www.my4pcb.com/Net/Promotion/OrderFileUpload
NEW STUFF
2200 ohm | 6 | https://www.digikey.com/en/products/detail/yageo/RC0603FR-072K2L/727016 | https://www.mouser.com/ProductDetail/YAGEO/RC0603FR-072K2L?qs=diQw95jMAeOQmNpe2MM%252BPw%3D%3D | 0.1 | 0.6
10k ohm | 17 | https://www.digikey.com/en/products/detail/bourns-inc/CR0603-FX-1002ELF/3593188 | https://www.mouser.com/ProductDetail/Bourns/CR0603-FX-1002ELF?qs=K5ddiUFZPT6XHG0dQH96QA%3D%3D | 0.1 | 1.7
47u caps | 2 | https://www.digikey.com/en/products/detail/murata-electronics/GRM188R60J476ME15D/5877410 | https://www.mouser.com/ProductDetail/Murata-Electronics/GRM188R60J476ME15D?qs=AEetWsPH0It1A1GvJsMuyQ%3D%3D | 0.41 | 0.82
1u cap | 3 | https://www.digikey.com/en/products/detail/nichicon/UUP1H0R1MCL1GS/2550398 | https://www.mouser.com/ProductDetail/Nichicon/UUP1H0R1MCL1GS?qs=huzeVNXgovXvQmoxbanaNw%3D%3D | 0.71 | 2.13
10u cap | 2 | https://www.digikey.com/en/products/detail/taiyo-yuden/LMK107BBJ106MALT/3662195 | https://www.mouser.com/ProductDetail/TAIYO-YUDEN/LMK107BBJ106MALT?qs=qEEMd6hQM8WopRGPMVpb1A%3D%3D | 0.14 | 0.28
470u cap | 4 | https://www.digikey.com/en/products/detail/nichicon/UWT1C471MNL1GS/589922 | https://www.mouser.com/ProductDetail/Nichicon/UWT1C471MNL1GS?qs=xhd8%2FJ0uCryvN24ScGEHow%3D%3D | 0.53 | 2.12
150 ohm | 1 | https://www.digikey.com/en/products/detail/bourns-inc/CR0603-FX-1500ELF/3783747 | https://www.mouser.com/ProductDetail/KEMET/C0603C104K3RACTU?qs=l5k%252BbMnNDklvfdneglCDAg%3D%3D | 0.1 | 0.1
100n cap | 2 | https://www.digikey.com/en/products/detail/kemet/C0603C104K3RACTU/416044 | https://www.mouser.com/ProductDetail/KEMET/C0603C104K3RACTU?qs=l5k%252BbMnNDklvfdneglCDAg%3D%3D | 0.1 | 0.2
1 ohm | 2 | https://www.digikey.com/en/products/detail/bourns-inc/CR0603-J-1R0ELF/3784235 | https://www.mouser.com/ProductDetail/Bourns/CR0603-J-1R0ELF?qs=qoM5eaYTVMOn1x0%252BMzgpdg%3D%3D | 0.1 | 0.2
100u cap | 1 | https://www.digikey.com/en/products/detail/w%C3%BCrth-elektronik/865080343009/5728014 | https://www.mouser.com/ProductDetail/Wurth-Elektronik/865080343009?qs=0KOYDY2FL28Gid9q%2FqirTQ%3D%3D | 0.29 | 0.29
1k ohm | 1 | https://www.digikey.com/en/products/detail/bourns-inc/CR0603-JW-102ELF/3741004 | https://www.mouser.com/ProductDetail/Bourns/CR0603-JW-102ELF?qs=rcPhh2wube3o3zlmFZCUPg%3D%3D | 0.1 | 0.1
1.3k ohm | 1 | https://www.digikey.com/en/products/detail/bourns-inc/CR0603-FX-1301ELF/3783719 | https://www.mouser.com/ProductDetail/Bourns/CR0603-FX-1301ELF?qs=e7cxVwPieuqy%252BILjxvjWKw%3D%3D | 0.1 | 0.1
3.3v converter | 1 | https://www.digikey.com/en/products/detail/evvo/AMS1117-3-3/22482148 | https://www.mouser.com/ProductDetail/Texas-Instruments/LM1117MPX-3.3-NOPB?qs=X1J7HmVL2ZHRbBIxXi4utg%3D%3D | 0.29 | 0.29
breadboard to jstxh | 8 | https://www.digikey.com/en/products/detail/adafruit-industries-llc/5755/21839804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 | https://www.mouser.com/ProductDetail/Adafruit/5755?qs=mELouGlnn3enIDY14Zj52w%3D%3D | 1.5 | 12
wire to jstxh | 2 | https://www.digikey.com/en/products/detail/adafruit-industries-llc/3950/9745249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 | https://www.mouser.com/ProductDetail/Adafruit/3950?qs=byeeYqUIh0P%2FtwUHCsW1%252BQ%3D%3D | 1.5 | 3
wire to jstph | 6 | https://www.digikey.com/en/products/detail/analog-devices-inc-maxim-integrated/CABLE-PH05/9381901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 | https://www.mouser.com/ProductDetail/Analog-Devices-Maxim-Integrated/CABLE-PH05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 | 1.47 | 8.82
microswitch wire | 1 | https://www.digikey.com/en/products/detail/adafruit-industries-llc/4046/9843409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 | https://www.mouser.com/ProductDetail/Adafruit/4046?qs=vLWxofP3U2ybM%2FazkaSZDQ%3D%3D | 0.95 | 0.95
wires | 10 | https://www.digikey.com/en/products/detail/3m/3811-10-300/1107526 | https://www.mouser.com/ProductDetail/3M-Electronic-Solutions-Division/3811-10-300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 | 1.18 | 11.8
12V motor | 1 | https://www.digikey.com/en/products/detail/pololu/3474/10450150 | https://www.pololu.com/product/3474 | 0 | 0 | Not used
wire to jstxh 2 terminal | 1 | https://www.digikey.com/en/products/detail/adafruit-industries-llc/261/5353586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 | https://www.mouser.com/ProductDetail/Adafruit/261?qs=GURawfaeGuDeA9XsXeF0ug%3D%3D | 0.75 | 0.75
jstxh 2 terminal | 1 | https://www.digikey.com/en/products/detail/jst-sales-america-inc/B2B-XH-A/1651045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 | https://www.mouser.com/ProductDetail/JST-Commercial/B2B-XH-ALFSN?qs=cdbOS8ANM9DdcSn9qRmfCw%3D%3D | 0.1 | 0.1
usb a to a cable | 1 | https://www.digikey.com/en/products/detail/my-cable-mart/FE-USB3-AA-06IN/24373315 | https://www.mouser.com/ProductDetail/StarTech/USB2AA1M?qs=PBDs2xEllI%252BGjA4r05Y5ag%3D%3D | 0 | 0 | Not used
ESP32 Headers | 2 | https://www.digikey.com/en/products/detail/sullins-connector-solutions/PPTC191LFBN-RC/810157 | https://www.mouser.com/ProductDetail/Samtec/BCS-119-L-S-TE?qs=0lQeLiL1qya%252BYtumhpXrhg%3D%3D | 3.67 | 7.34
driver motor headers | 1 | https://www.digikey.com/en/products/detail/adafruit-industries-llc/85/5154649 | https://www.mouser.com/ProductDetail/Adafruit/85?qs=GURawfaeGuDpvKgGcAWEWQ%3D%3D | 1.95 | 1.95
 |  |  |  |  | 94.71

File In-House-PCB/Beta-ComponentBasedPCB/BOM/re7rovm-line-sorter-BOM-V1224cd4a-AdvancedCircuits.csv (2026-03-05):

Component Description | QTY | Ref Des | Mfg P/N # | Manufacturer | Distributor P/N #
Non-Polarized Capacitor, 0.1uF, SMD_0603_1608Metric | 2 | C1,Up
Non-Polarized Capacitor, 47uF, CP_Radial_D6.3mm_P2.50mm | 2 | C2,C9
Non-Polarized Capacitor, 1uF, SMD_0603_1608Metric | 1 | C3
Non-Polarized Capacitor, 100nF, SMD_0603_1608Metric | 2 | C5,C8
Non-Polarized Capacitor, 10nF, SMD_0603_1608Metric | 1 | C7
Schottky Barrier Diodes (SBD), SMB_L4.3-W3.6-LS5.4-RD | 7 | D1,D14,D15,D16,D17,D8,D9 | SS34 | UMW(友台半导体)
Diode | 1 | D2 | SMBJ24A | Littelfuse Inc.
Diodes - General Purpose, DO-41_BD2.4-L4.7-P8.70-D0.9-RD | 2 | D3,D4 | 1N4002-T | DIODES(美台)
Non-Polarized Capacitor, .33uF, SMD_0603_1608Metric | 1 | Down
Fuse | 1 | F1 | 05200101Z | Littelfuse Inc.
Integrated Circuit | 1 | IC1 | DRV8825PWPR | Texas Instruments Inc.
Connector | 5 | J1,J11,J12,J13,J2 | B3B-XH-A(LF)(SN) | JST Sales America Inc.
Connector | 1 | J3 | S4P-VH | JST Sales America Inc.
Connector | 5 | J5,J6,J7,J8,J9 | B2B-PH-K-S(LF)(SN) | JST Sales America
USB A | 1 | J10 | 61400416021 | Würth Elektronik
Connector | 4 | J14,J16,J17,J4 | 1-2834011-6 | TE Connectivity AMP Connectors
Connector, THT | 1 | J15 | 0022232031 | Molex
Inductor, 22uH, SMD_SRN6045TA | 1 | L1
MOSFETs, SOT-23-3_L2.9-W1.3-P1.90-LS2.4-BR | 5 | Q1,Q6,Q7,Q8,Q9 | AO3400A | UMW(友台半导体)
Resistor, 100Ω, SMD_0603_1608Metric | 5 | R1,R2,R36,R38,R40
Resistor, 150Ω, SMD_0603_1608Metric | 1 | R3
Resistor, 1300Ω, SMD_0603_1608Metric | 1 | R4
Resistor, 10kΩ, SMD_0603_1608Metric | 11 | R11,R12,R18,R27,R28,R29,R30,R31,R32,R33,R34
Resistor, 100kΩ, SMD_0603_1608Metric | 8 | R17,R25,R26,R35,R37,R39,R41,R6
Resistor, 1kΩ, SMD_0603_1608Metric | 2 | R23,R24
Switch | 1 | SW2 | 200MSP1T1B1M2QEH | E-Switch
Pin Headers, HDR-TH_26P-P2.54-V-M-R2-C13-S2.54-2 | 1 | U1 | X5521WV-2x13-C40D40-1196 | XKB Connection(中国星坤)
Integrated Circuit | 1 | U2 | TPS54302DDCR | Texas Instruments
Operational Amplifier (OP-AMP) | 1 | U3 | OPA340UA | Texas Instruments
Integrated Circuit | 1 | U5 | LM7805CT/NOPB | Texas Instruments
Integrated Circuit | 1 | U6 | LM338T/NOPB | Texas Instruments

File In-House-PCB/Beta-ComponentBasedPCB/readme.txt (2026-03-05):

Project Name: Line Sorter
Project Version: #1224cd4a
Project Url: https://www.flux.ai/re7rovm/line-sorter

Project Description:
Welcome to your new project. Imagine what you can build here.

Project Properties:

System Architecture:

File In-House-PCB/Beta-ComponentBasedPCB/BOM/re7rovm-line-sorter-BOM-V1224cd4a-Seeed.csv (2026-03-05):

Designator | Manufacturer Part Number or Seeed SKU | QTY | Link
C1,Up |  | 2
C2,C9 |  | 2
C3 |  | 1
C5,C8 |  | 2
C7 |  | 1
D1,D14,D15,D16,D17,D8,D9 | SS34 | 7
D2 | SMBJ24A | 1
D3,D4 | 1N4002-T | 2
Down |  | 1
F1 | 05200101Z | 1
IC1 | DRV8825PWPR | 1
J1,J11,J12,J13,J2 | B3B-XH-A(LF)(SN) | 5
J3 | S4P-VH | 1
J5,J6,J7,J8,J9 | B2B-PH-K-S(LF)(SN) | 5
J10 | 61400416021 | 1
J14,J16,J17,J4 | 1-2834011-6 | 4
J15 | 0022232031 | 1
L1 |  | 1
Q1,Q6,Q7,Q8,Q9 | AO3400A | 5
R1,R2,R36,R38,R40 |  | 5
R3 |  | 1
R4 |  | 1
R11,R12,R18,R27,R28,R29,R30,R31,R32,R33,R34 |  | 11
R17,R25,R26,R35,R37,R39,R41,R6 |  | 8
R23,R24 |  | 2
SW2 | 200MSP1T1B1M2QEH | 1
U1 | X5521WV-2x13-C40D40-1196 | 1
U2 | TPS54302DDCR | 1
U3 | OPA340UA | 1
U5 | LM7805CT/NOPB | 1
U6 | LM338T/NOPB | 1

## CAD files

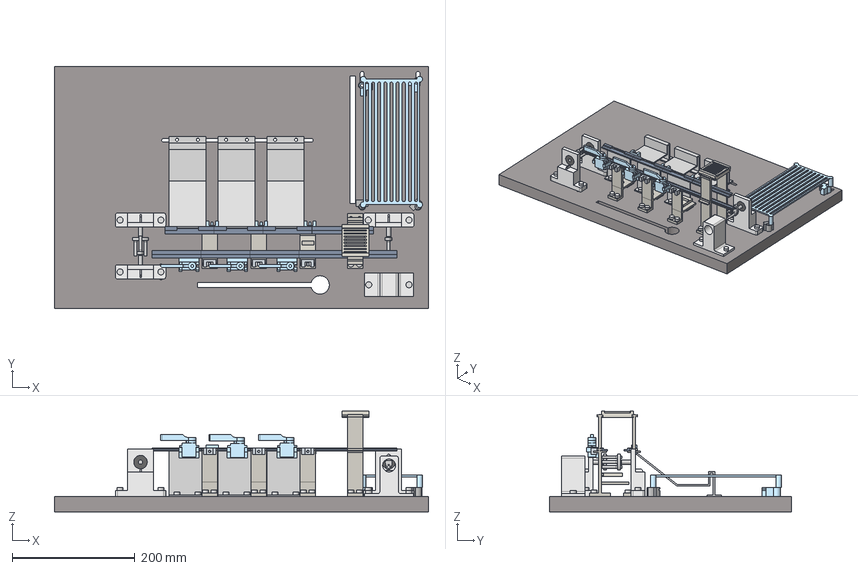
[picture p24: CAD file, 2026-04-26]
Full Assembly.step
609.6 x 393.7 x 164.3 mm

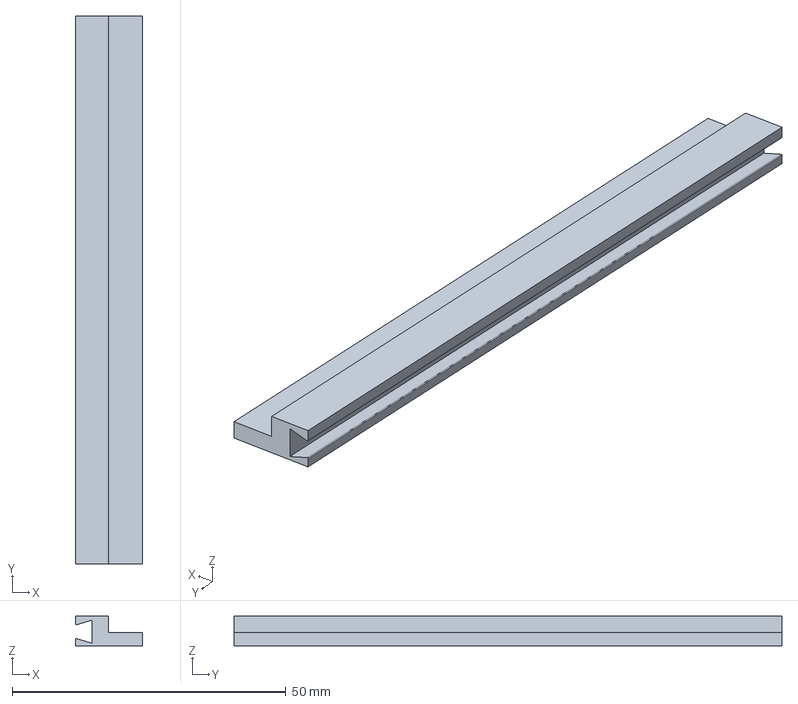
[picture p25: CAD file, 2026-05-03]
Final Parts and Assembly/Long Rail - Long Rail.step
12.2 x 100.0 x 5.45 mm

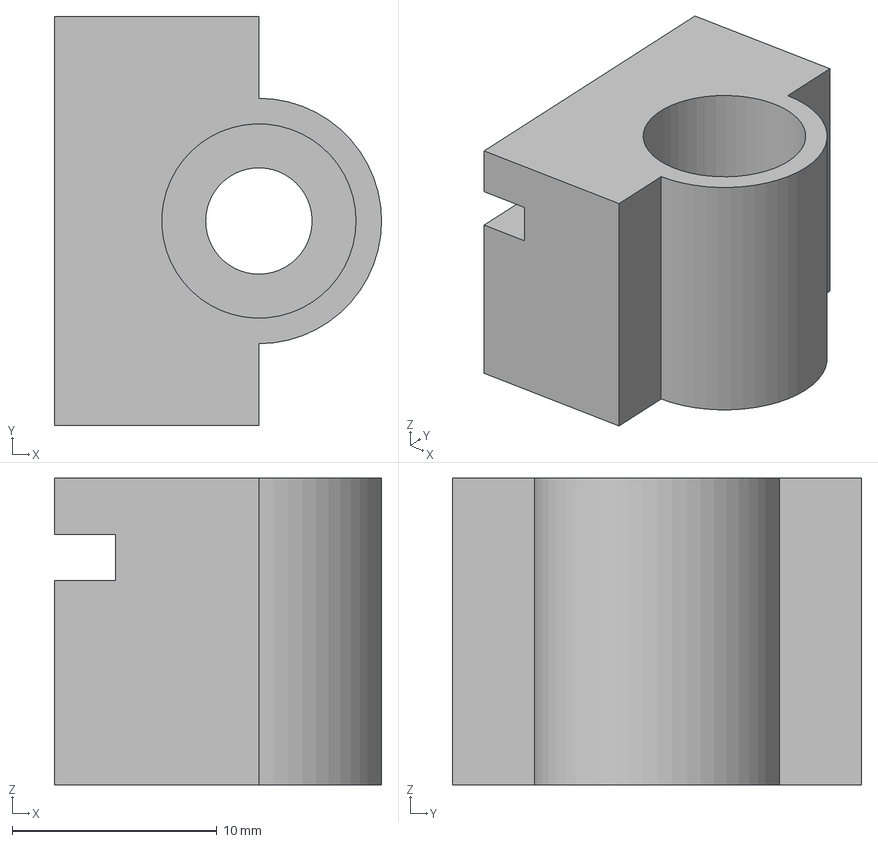
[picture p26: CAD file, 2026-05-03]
Final Parts and Assembly/PCB Holder (side) - Part 1.step
16.0 x 20.0 x 15.0 mm

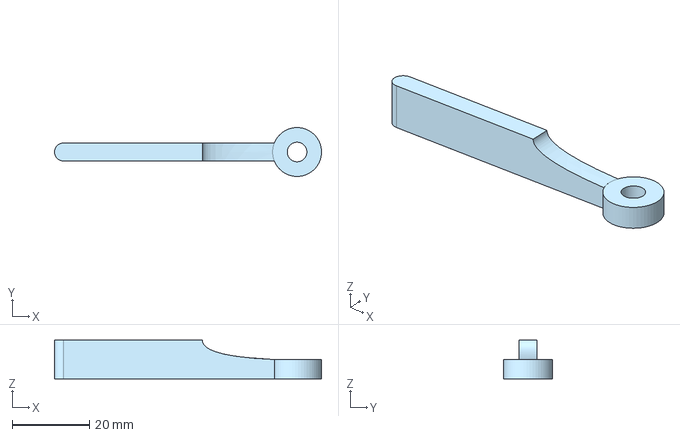
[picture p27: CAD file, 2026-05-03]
Final Parts and Assembly/Lever Arm - Servo Lever Arm.step
69.3 x 12.7 x 10.0 mm

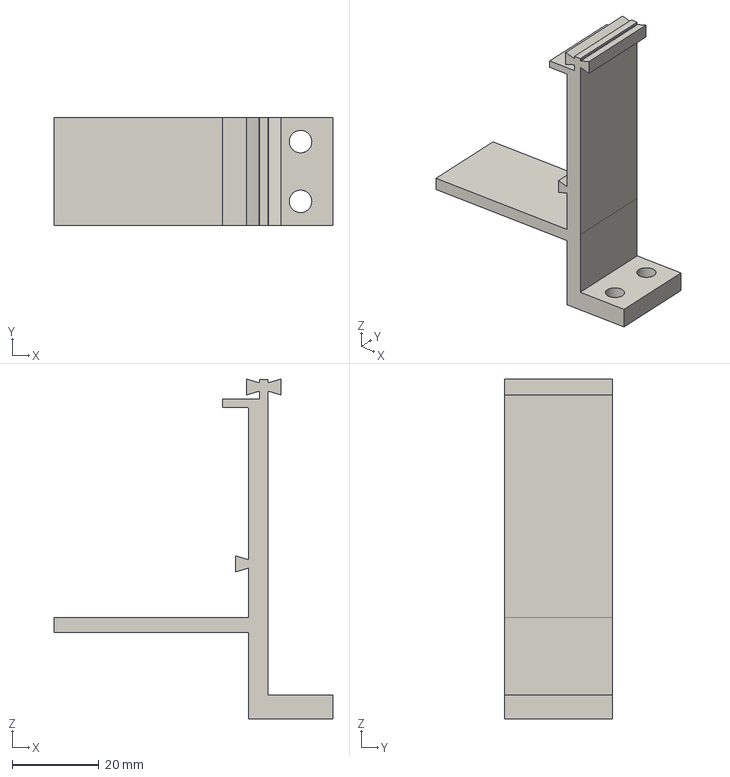
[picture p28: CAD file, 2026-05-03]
Final Parts and Assembly/Leg - Leg.step
64.5 x 25.0 x 78.6 mm

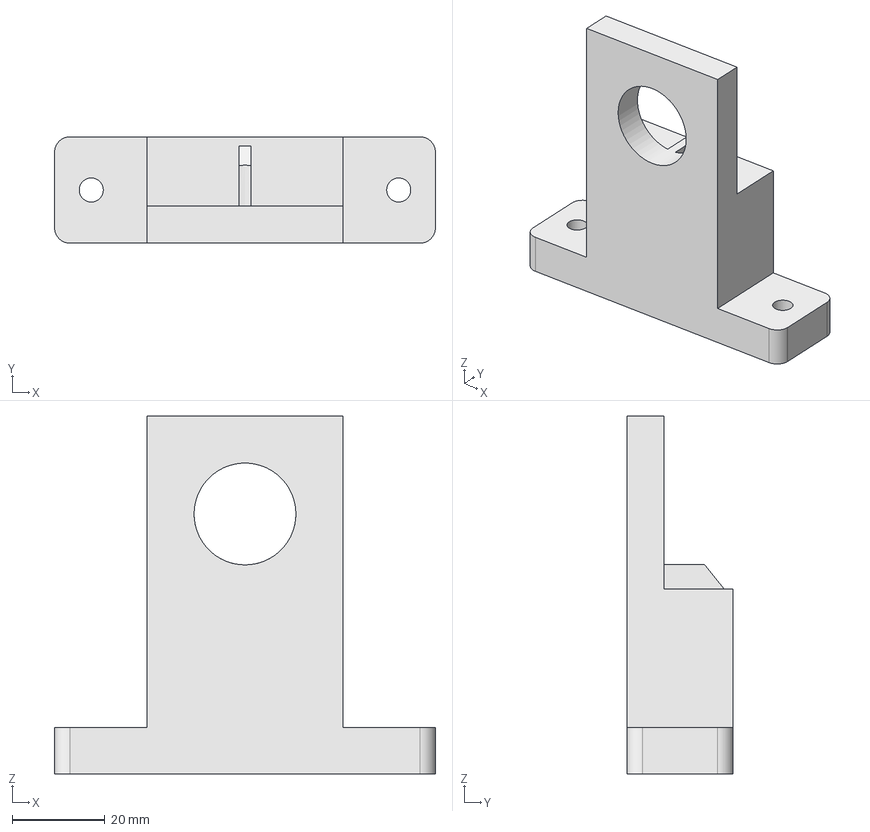
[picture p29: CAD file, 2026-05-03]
Final Parts and Assembly/Bearing Mount - Part 1.step
82.3 x 23.0 x 77.3 mm

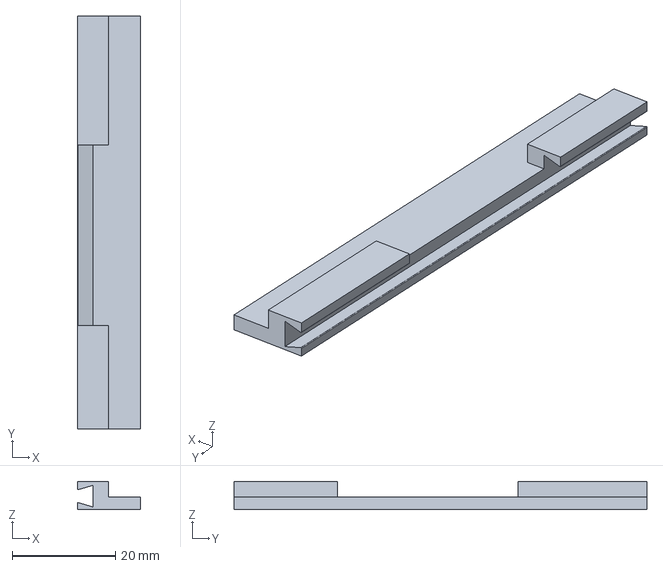
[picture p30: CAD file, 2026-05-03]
Final Parts and Assembly/Rail for Ramp - Rail for Ramp.step
12.2 x 80.0 x 5.45 mm

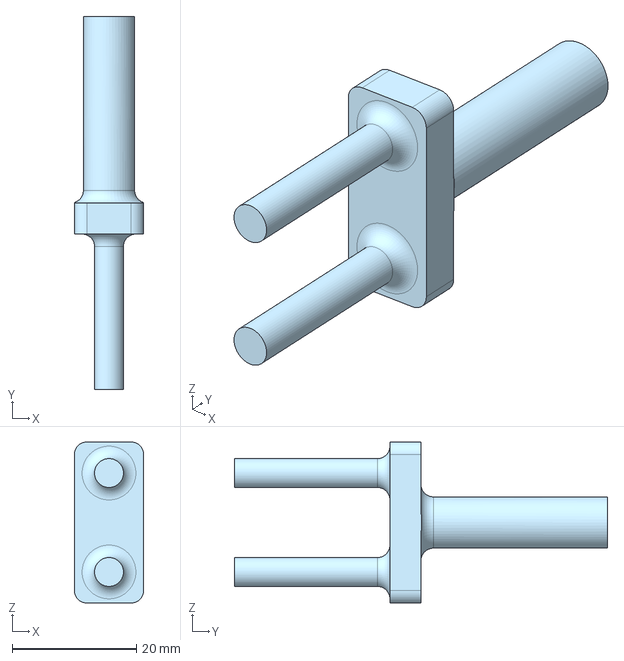
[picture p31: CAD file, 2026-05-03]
Final Parts and Assembly/Adapter (Bearing Side) - Bearing Adapter.step
11.1 x 60.0 x 25.9 mm

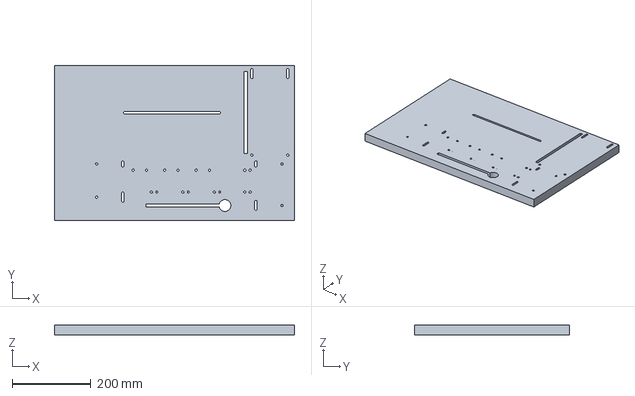
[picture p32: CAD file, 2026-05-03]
Final Parts and Assembly/Baseplate sketch - Baseplate.step
609.6 x 393.7 x 25.0 mm

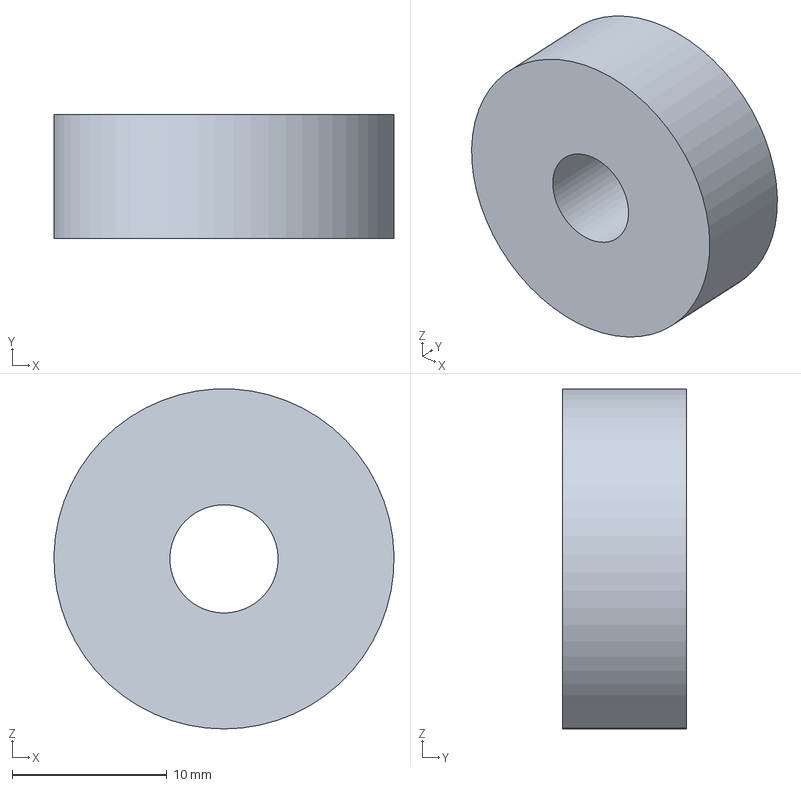
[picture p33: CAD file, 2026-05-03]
Final Parts and Assembly/Part Studio 1 - Part 1.step
22.0 x 8.00 x 22.0 mm

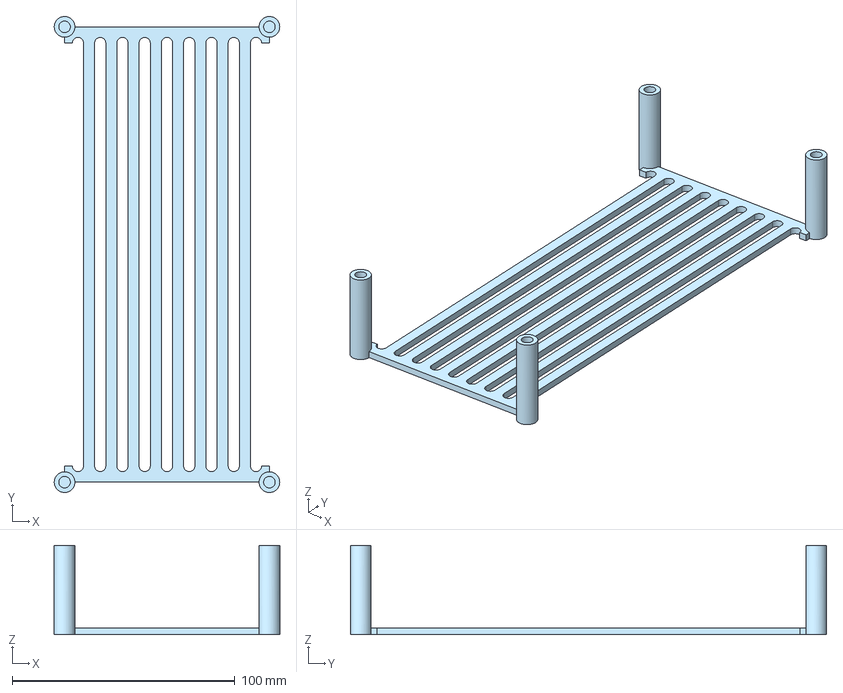
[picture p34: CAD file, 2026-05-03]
Final Parts and Assembly/PCB Cover - PCB Cover.step
101.3 x 213.8 x 40.0 mm

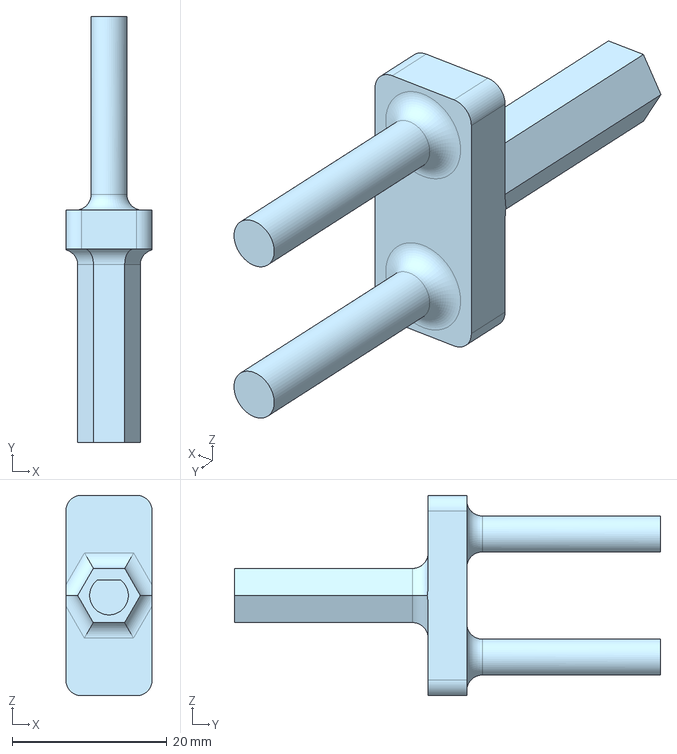
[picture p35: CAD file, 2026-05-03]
Final Parts and Assembly/Adapter (Motor Side) - Part 1.step
11.1 x 55.0 x 25.9 mm

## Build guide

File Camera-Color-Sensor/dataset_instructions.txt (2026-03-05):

1. Download the dataset from: https://www.kaggle.com/datasets/adikurniawan/color-dataset-for-color-recognition/data
2. Extract the dataset into a folder named "training_dataset" in the project root.
3. The "dataset" folder should contain subfolders for each color, e.g.:
   dataset/
     Red/
       img1.jpg, img2.jpg...
     Blue/
       ...
     Green/
       ...
4. Run "python train_model.py" to train the color recognition model.
5. Run "python color_recognition.py" to start the live feed.

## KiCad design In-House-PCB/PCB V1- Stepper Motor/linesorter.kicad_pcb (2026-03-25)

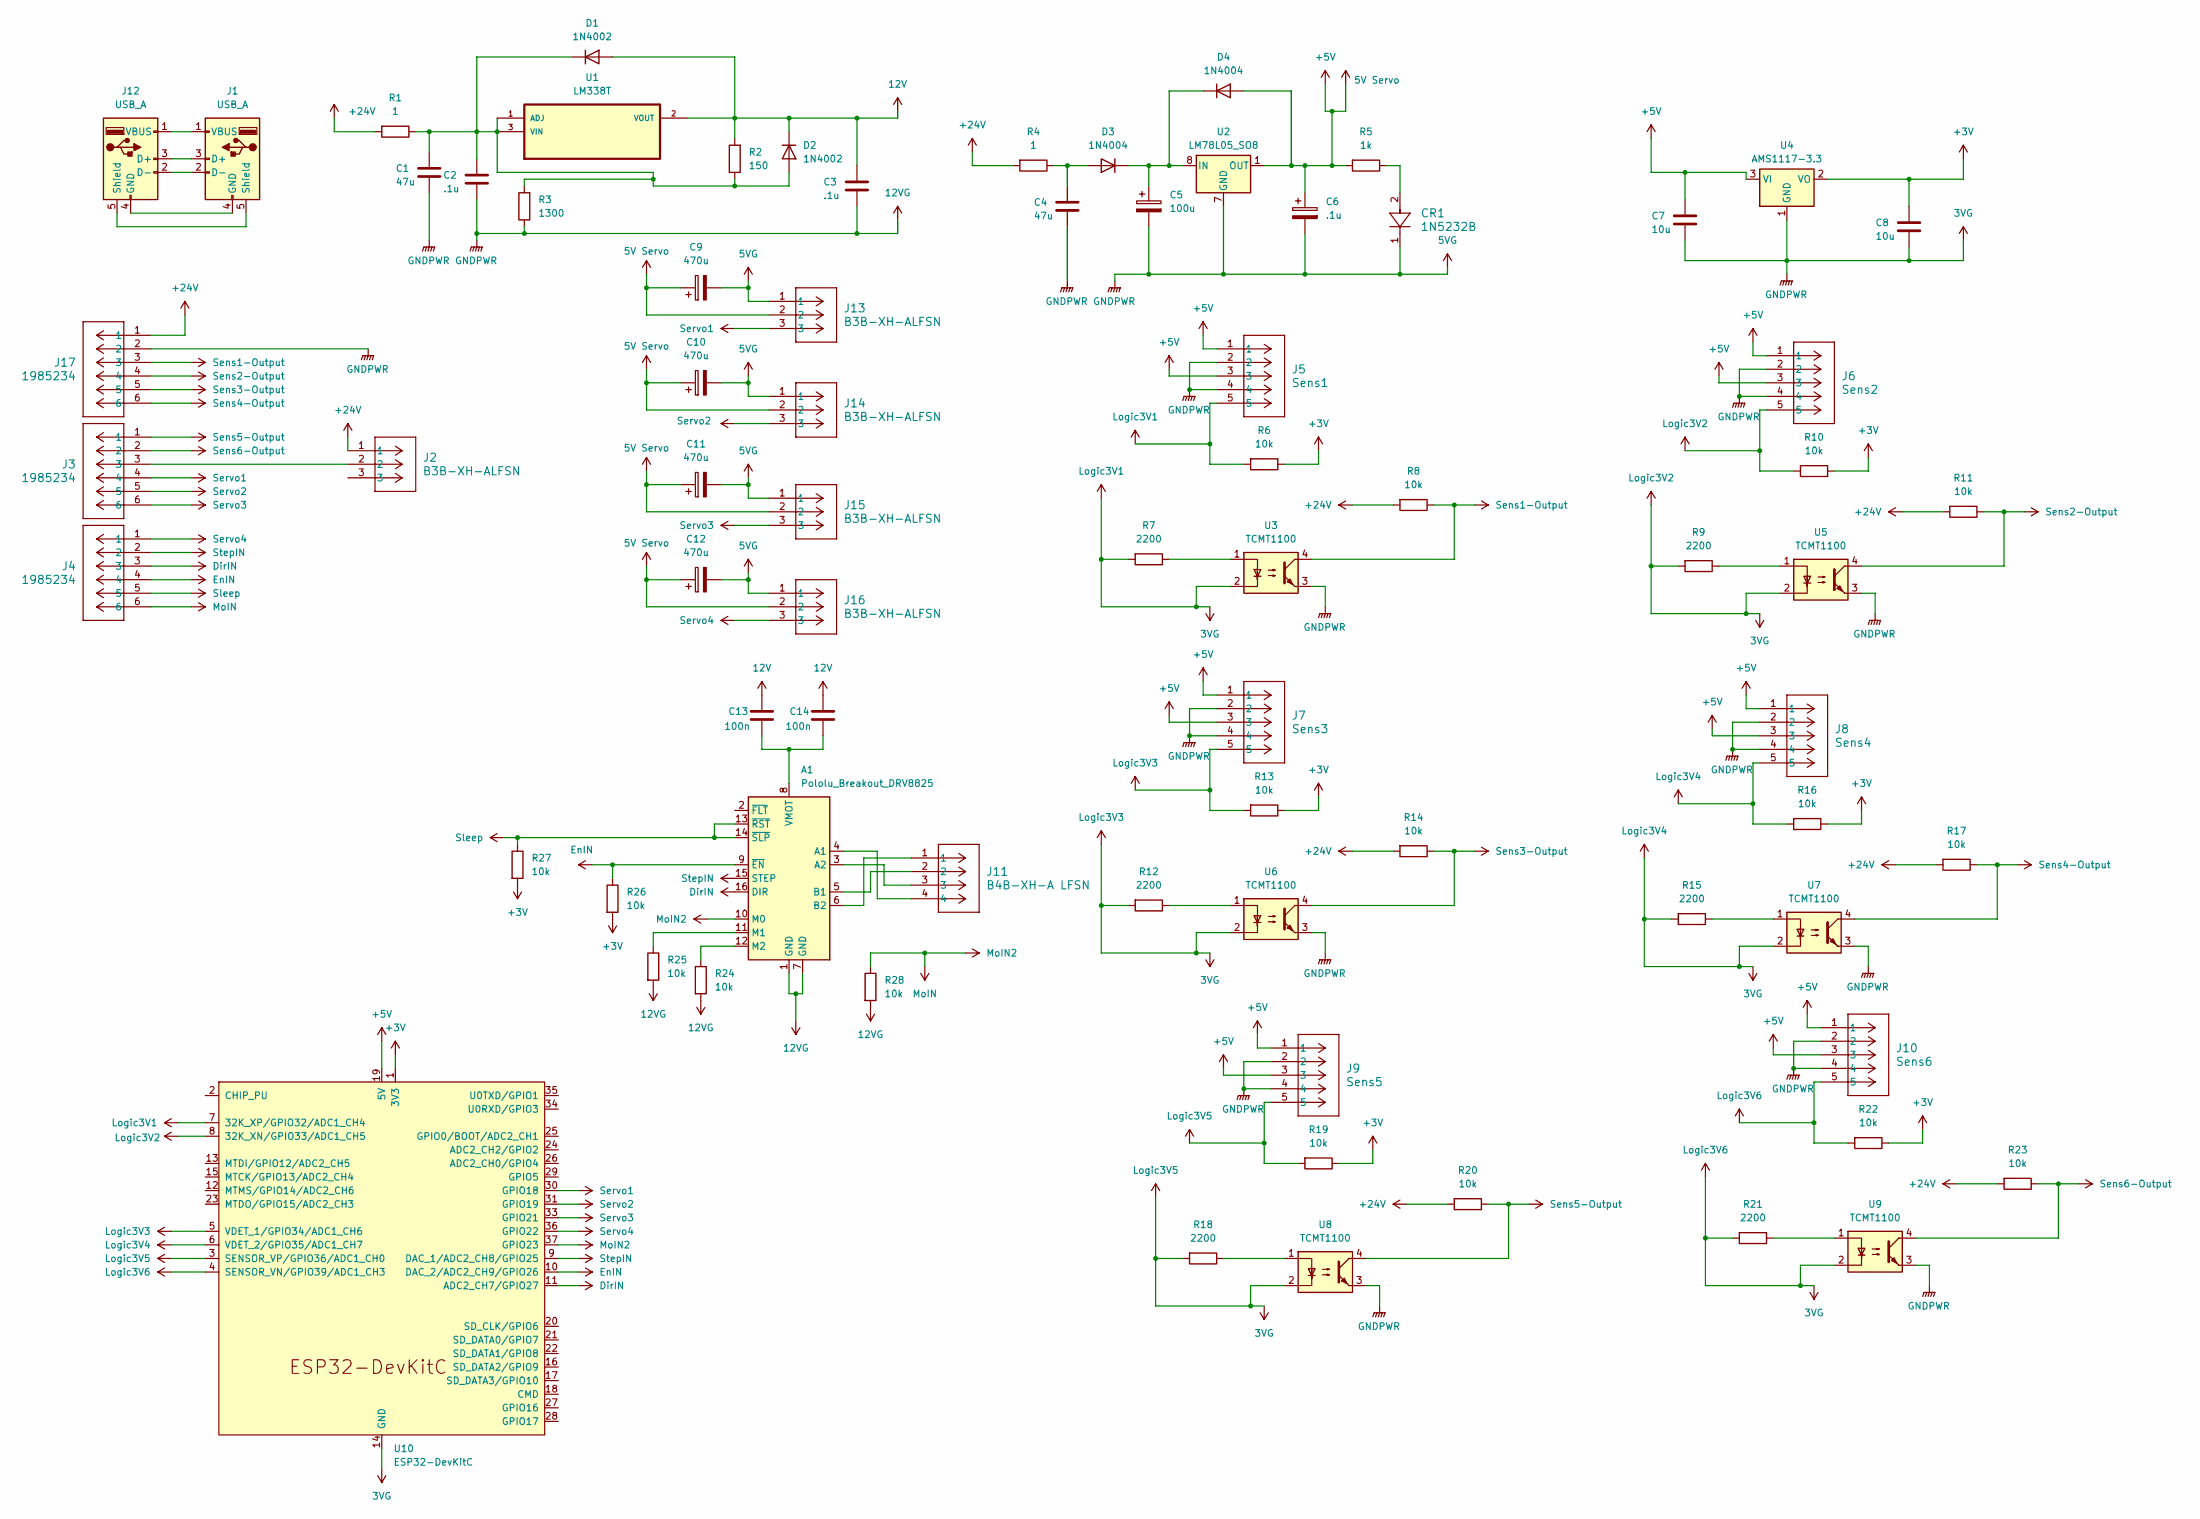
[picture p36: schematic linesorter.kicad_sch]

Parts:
A1: Pololu_Breakout_DRV8825; Pololu_Breakout-16_15.2x20.3mm
C1, C4: 47u; C_0201_0603Metric
C2, C3: .1u; C_0201_0603Metric
C5: 100u; CP_Elec_3x5.3
C6: .1u; CP_Elec_3x5.3
C7, C8: 10u; C_0201_0603Metric
C9, C10, C11, C12: 470u; CP_Elec_3x5.3
C13, C14: 100n; C_0201_0603Metric
CR1: 1N5232B; AFL-W2C8.9D
D1, D2: 1N4002; D_DO-41_SOD81_P10.16mm_Horizontal
D3, D4: 1N4004; D_DO-41_SOD81_P10.16mm_Horizontal
J1, J12: USB_A; USB_A_Connfly_DS1095
J2, J13, J14, J15, J16: B3B-XH-ALFSN; CONN_B3B-XH-A_JST
J3, J4, J17: 1985234; CONN_1985234
J5: Sens1; CONN_S5B-PH-K-S_JST
J6: Sens2; CONN_S5B-PH-K-S_JST
J7: Sens3; CONN_S5B-PH-K-S_JST
J8: Sens4; CONN_S5B-PH-K-S_JST
J9: Sens5; CONN_S5B-PH-K-S_JST
J10: Sens6; CONN_S5B-PH-K-S_JST
J11: B4B-XH-A LFSN; CONN_B4B-XH-A LFSN_JST
R1, R4: 1; R_0201_0603Metric
R2: 150; R_0201_0603Metric
R3: 1300; R_0201_0603Metric
R5: 1k; R_0201_0603Metric
R6, R8, R10, R11, R13, R14, R16, R17, R19, R20, R22, R23, R24, R25, R26, R27, R28: 10k; R_0201_0603Metric
R7, R9, R12, R15, R18, R21: 2200; R_0201_0603Metric
U1: LM338T; TO254P1054X470X1955-3
U2: LM78L05_SO8; SOIC-8_3.9x4.9mm_P1.27mm
U3, U5, U6, U7, U8, U9: TCMT1100; SOP-4_4.4x2.6mm_P1.27mm
U4: AMS1117-3.3; SOT-223-3_TabPin2
U10: ESP32-DevKitC

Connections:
12V: C3.1, C13.1, C14.1, D1.2 (A), D2.1 (K), R2.2, U1.2 (VOUT)
12VG: A1.1 (GND), A1.7 (GND), C1.2, C2.2, C3.2, C4.2, C5.2, C6.2, C7.2, C8.2, C9.2, C10.2, C11.2, C12.2, CR1.1, J5.2, J5.4, J5.5, J6.2, J6.4, J6.5, J7.2, J7.4, J7.5, J8.2, J8.4, J8.5, J9.2, J9.4, J9.5, J10.2, J10.4, J10.5, J13.1, J14.1, J15.1, J16.1, J17.2, R3.1, R6.2, R7.2, R9.2, R10.2, R12.2, R13.2, R15.2, R16.2, R18.2, R19.2, R21.2, R22.2, R24.2, R25.2, R28.2, U2.2 (GND), U2.3 (GND), U2.6 (GND), U2.7 (GND), U3.2, U3.3, U4.1 (GND), U5.2, U5.3, U6.2, U6.3, U7.2, U7.3, U8.2, U8.3, U9.2, U9.3, U10.3 (SENSOR_VP/GPIO36/ADC1_CH0), U10.4 (SENSOR_VN/GPIO39/ADC1_CH3), U10.5 (VDET_1/GPIO34/ADC1_CH6), U10.6 (VDET_2/GPIO35/ADC1_CH7), U10.7 (32K_XP/GPIO32/ADC1_CH4), U10.8 (32K_XN/GPIO33/ADC1_CH5), U10.14 (GND), U10.32 (GND), U10.38 (GND)
+3V: C8.1, R6.1, R10.1, R13.1, R16.1, R19.1, R22.1, R26.2, R27.2, U4.2 (VO), U10.1 (3V3)
+5V: C6.1, C7.1, C9.1, C10.1, C11.1, C12.1, D4.2 (A), J5.1, J5.3, J6.1, J6.3, J7.1, J7.3, J8.1, J8.3, J9.1, J9.3, J10.1, J10.3, J13.2, J14.2, J15.2, J16.2, R5.2, U2.1 (OUT), U4.3 (VI), U10.19 (5V)
+24V: J2.1, J17.1, R1.2, R4.2, R8.2, R11.2, R14.2, R17.2, R20.2, R23.2
DirIN: A1.16 (DIR), J4.3, U10.11 (ADC2_CH7/GPIO27)
EnIN: A1.9 (~EN), J4.4, R26.1, U10.10 (DAC_2/ADC2_CH9/GPIO26)
MoIN: A1.10 (M0), J4.6, R28.1, U10.37 (GPIO23)
unnamed: A1.4 (A1), J11.4
unnamed: A1.3 (A2), J11.3
unnamed: A1.5 (B1), J11.2
unnamed: A1.6 (B2), J11.1
unnamed: A1.11 (M1), R25.1
unnamed: A1.12 (M2), R24.1
unnamed: A1.8 (VMOT), C13.2, C14.2
unnamed: CR1.2, R5.1
unnamed: C1.1, C2.1, D1.1 (K), D2.2 (A), R1.1, R2.1, R3.2, U1.1 (ADJ), U1.3 (VIN)
unnamed: C4.1, D3.2 (A), R4.1
unnamed: C5.1, D3.1 (K), D4.1 (K), U2.8 (IN)
unnamed: J1.3 (D+), J12.3 (D+)
unnamed: J1.2 (D-), J12.2 (D-)
unnamed: J1.4 (GND), J12.4 (GND)
unnamed: J1.5 (Shield), J12.5 (Shield)
unnamed: J1.1 (VBUS), J12.1 (VBUS)
unnamed: J2.2, J3.3
unnamed: R7.1, U3.1
unnamed: R9.1, U5.1
unnamed: R12.1, U6.1
unnamed: R15.1, U7.1
unnamed: R18.1, U8.1
unnamed: R21.1, U9.1
Sens1-Output: J17.3, R8.1, U3.4
Sens2-Output: J17.4, R11.1, U5.4
Sens3-Output: J17.5, R14.1, U6.4
Sens4-Output: J17.6, R17.1, U7.4
Sens5-Output: J3.1, R20.1, U8.4
Sens6-Output: J3.2, R23.1, U9.4
Servo1: J3.4, J13.3, U10.30 (GPIO18)
Servo2: J3.5, J14.3, U10.31 (GPIO19)
Servo3: J3.6, J15.3, U10.33 (GPIO21)
Servo4: J4.1, J16.3, U10.36 (GPIO22)
Sleep: A1.13 (~RST), A1.14 (~SLP), J4.5, R27.1
StepIN: A1.15 (STEP), J4.2, U10.9 (DAC_1/ADC2_CH8/GPIO25)

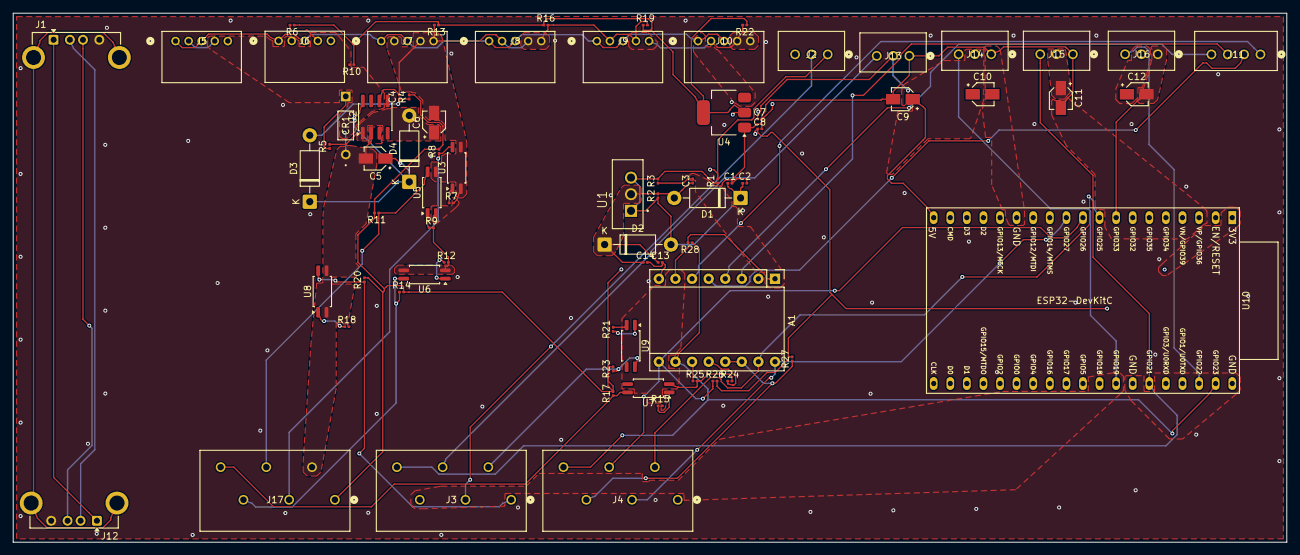
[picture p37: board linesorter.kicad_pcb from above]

Board: 2 copper layers, 195.0 x 81.0 mm, 75 parts (0 on the bottom side), 43 nets.

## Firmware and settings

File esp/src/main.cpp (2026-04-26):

#include <Arduino.h>
#include <ESP32Servo.h>
#include <AccelStepper.h>

// PIN STUFF
// Stepper
const int STEPPER_STEP_PIN   = 23;
const int STEPPER_DIR_PIN    = 27;
//const int STEPPER_ENABLE_PIN = 26; //controlled by RevPi to switch conveyor on/off

// RevPi Digital Outputs
const int WHITE_SERVO_CTRL = 39; //uses pin for 5th breakbeam, control signal from RevPi for white servo acutation
const int RED_SERVO_CTRL = 32; //uses pin for 6th breakbeam, control signal from RevPi for red servo acutation
//const int BLUE_SERVO_CTRL = 21 //uses pin for 4th servo, control signal from RevPi for blue servo acutation

static int lastWhiteState = -1;
static int lastRedState = -1;
static int lastBlueState = -1;


// Servos
const int SERVO_1_PIN = 18; // White Gate
const int SERVO_2_PIN = 19; // Red Gate
//const int SERVO_3_PIN = 20; // Blue Gate, GPIO20 does not exist on ESP, unable to be implemented at this pin


const int GATE_CLOSED = 0;
const int GATE_OPEN   = 126;

// HARDWARE 
AccelStepper beltStepper(AccelStepper::DRIVER, STEPPER_STEP_PIN, STEPPER_DIR_PIN);
Servo gateWhite;
Servo gateRed;
//Servo gateBlue;

void setup() {

  // Stepper setup
  //pinMode(STEPPER_ENABLE_PIN, OUTPUT);
  //digitalWrite(STEPPER_ENABLE_PIN, HIGH);

  beltStepper.setMaxSpeed(1000);
  beltStepper.setSpeed(50); //counts per second, stepper motor has 200 counts/rev 

  pinMode(WHITE_SERVO_CTRL, INPUT);
  pinMode(RED_SERVO_CTRL, INPUT);
  //pinMode(BLUE_SERVO_CTRL, INPUT);

  // Servos
  gateWhite.attach(SERVO_1_PIN, 500, 2400);
  gateRed.attach(SERVO_2_PIN,   500, 2400);
  //gateBlue.attach(SERVO_3_PIN,  500, 2400);

  gateWhite.write(GATE_CLOSED);
  gateRed.write(GATE_CLOSED);
  //gateBlue.write(GATE_CLOSED);

  lastWhiteState = digitalRead(WHITE_SERVO_CTRL);
  lastRedState   = digitalRead(RED_SERVO_CTRL);
  //lastBlueState  = digitalRead(BLUE_SERVO_CTRL);
}

void loop() {
  int currentWhiteState = digitalRead(WHITE_SERVO_CTRL);
  int currentRedState = digitalRead(RED_SERVO_CTRL);
  //int currentBlueState = digitalRead(BLUE_SERVO_CTRL);

  if (currentWhiteState != lastWhiteState) { //only update servo state when control signal changes
    if (currentWhiteState == LOW) {
      gateWhite.write(GATE_CLOSED);
    } else {
      gateWhite.write(GATE_OPEN);
    }
    lastWhiteState = currentWhiteState;
  }
  if (currentRedState != lastRedState) {
    if (currentRedState == LOW) {
      gateRed.write(GATE_CLOSED);
    } else {
      gateRed.write(GATE_OPEN);
    }
    lastRedState = currentRedState;
  }

  beltStepper.runSpeed(); //stepper runs at constant speed

}

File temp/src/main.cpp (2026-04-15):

#include <Arduino.h>
#include <ESP32Servo.h>
#include <AccelStepper.h>

// PIN stuff 
const int DISTANCE_SWITCH = 4;
const int SERVO_1_PIN = 18; // White Gate
const int SERVO_2_PIN = 19; // Red Gate
const int SERVO_3_PIN = 22; // Blue Gate

// CALIBRATION - need to adjust these based on actual measurements 
const int CLICKS_TO_WHITE = 50;  // num Clicks from camera to Gate 1
const int CLICKS_TO_RED = 100;   // num Clicks from camera to Gate 2
const int CLICKS_TO_BLUE = 150;  // num Clicks from camera to Gate 3

const int GATE_CLOSED = 0;
const int GATE_OPEN = 126;       // 70% of 180 degrees
const unsigned long GATE_HOLD_TIME = 1000; // Time (ms) gate stays open

//  OBJECTS 
AccelStepper beltStepper(1, 14, 12); // (Type:Driver, StepPin, DirPin)
Servo gateWhite;
Servo gateRed;
Servo gateBlue;

// TRACKING VARIABLES 
// 'volatile' tells the ESP32 this variable changes in the background (via interrupt)
volatile unsigned long totalClicks = 0; 

// Struct to define a tracked puck (adding in queue for later))
struct TrackedPuck {
  char color;
  unsigned long targetClick;
};

// A queue to hold up (say 10 for now) pucks currently on the belt
const int MAX_PUCKS = 10;
TrackedPuck puckQueue[MAX_PUCKS];
int activePucks = 0;

// Variables to handle closing the gates (after certain amt of time)
unsigned long gateWhiteCloseTime = 0;
unsigned long gateRedCloseTime = 0;
unsigned long gateBlueCloseTime = 0;


// INTERRUPT SERVICE ROUTINE 
// This runs instantly every time the switch clicks
void IRAM_ATTR countClicks() {
  totalClicks++;
}

void setup() {
  Serial.begin(115200);

  // Setup Distance Switch Interrupt
  pinMode(DISTANCE_SWITCH, INPUT_PULLDOWN);
  attachInterrupt(digitalPinToInterrupt(DISTANCE_SWITCH), countClicks, RISING);

  // Setup Stepper (XY42STH34-0354A)
  beltStepper.setMaxSpeed(1000); 
  beltStepper.setSpeed(600); // Constant running speed

  // Setup Servos (Adafruit 169 limits)
  gateWhite.attach(SERVO_1_PIN, 500, 2400);
  gateRed.attach(SERVO_2_PIN, 500, 2400);
  gateBlue.attach(SERVO_3_PIN, 500, 2400);
  
  // Initializing gates to closed
  gateWhite.write(GATE_CLOSED);
  gateRed.write(GATE_CLOSED);
  gateBlue.write(GATE_CLOSED);
}

void loop() {
  // KEEP THE BELT MOVING //for this, it needs to stop under the camera for color sensing
  //todo change
  beltStepper.runSpeed();

  // CHECK FOR REVPI COMMANDS for puck info
  if (Serial.available() > 0) {
    char cmd = Serial.read();
    
    if ((cmd == 'W' || cmd == 'R' || cmd == 'B') && activePucks < MAX_PUCKS) {
      // Calculate where this specific puck needs to go
      unsigned long target = 0;
      if (cmd == 'W') target = totalClicks + CLICKS_TO_WHITE;
      if (cmd == 'R') target = totalClicks + CLICKS_TO_RED;
      if (cmd == 'B') target = totalClicks + CLICKS_TO_BLUE;

      // Add to the tracking queue
      puckQueue[activePucks].color = cmd;
      puckQueue[activePucks].targetClick = target;
      activePucks++;
      
      Serial.println("Puck Added to Queue");
    }
  }

  //  CHECK IF ANY PUCK HAS REACHED ITS GATE
  for (int i = 0; i < activePucks; i++) {
    if (totalClicks >= puckQueue[i].targetClick) {
      
      // signal to correct gate and set its closing timer
      if (puckQueue[i].color == 'W') {
        gateWhite.write(GATE_OPEN);
        gateWhiteCloseTime = millis() + GATE_HOLD_TIME;
      } 
      else if (puckQueue[i].color == 'R') {
        gateRed.write(GATE_OPEN);
        gateRedCloseTime = millis() + GATE_HOLD_TIME;
      } 
      else if (puckQueue[i].color == 'B') {
        gateBlue.write(GATE_OPEN);
        gateBlueCloseTime = millis() + GATE_HOLD_TIME;
      }

      // Remove puck from list w shift down
      for (int j = i; j < activePucks - 1; j++) {
        puckQueue[j] = puckQueue[j + 1];
      }
      activePucks--;
      i--; // Adjust index since we shifted array
    }
  }

  // CLOSE GATES after time 
  unsigned long currentTime = millis();
  
  if (gateWhiteCloseTime > 0 && currentTime >= gateWhiteCloseTime) {
    gateWhite.write(GATE_CLOSED);
    gateWhiteCloseTime = 0;
  }
  if (gateRedCloseTime > 0 && currentTime >= gateRedCloseTime) {
    gateRed.write(GATE_CLOSED);
    gateRedCloseTime = 0;
  }
  if (gateBlueCloseTime > 0 && currentTime >= gateBlueCloseTime) {
    gateBlue.write(GATE_CLOSED);
    gateBlueCloseTime = 0;
  }
}

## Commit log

2026-02-18 Mechanical: File relocation
    [Assembly 1 - Part 1 (1).step, Assembly 1 - Part 1 (2).step, Assembly 1 - Part 1 (3).step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]
2026-02-18 Alpha prototype PCB implementatioon
    [line-sorter-b_cu.gbr, line-sorter-b_mask.gbr, line-sorter-b_paste.gbr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]
2026-03-05 Beta Prototype update
    [line-sorter-b_cu.gbr, line-sorter-b_mask.gbr, line-sorter-b_paste.gbr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]
2026-03-05 init: camera color sensor implementation
2026-03-05 V1.0: Basic color sensor with live feed
2026-03-05 V1.01: Cameras recognized by name not number
2026-03-25 Electrical: PCB V1 Uploaded & Components added
    [linesorter-B_Adhesive.gbr, linesorter-B_Paste.gbr, linesorter-Board Layer Stack Bottom Overlay.gbr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]
2026-04-02 Color Sensor Code Update
2026-04-02 V2.01: Color Sensor RevPi Algorithm swapped
2026-04-08 Electrical: PCB V2 & Components Added
    [linesorter-B_Adhesive.gbr, linesorter-B_Paste.gbr, linesorter-Board Layer Stack Bottom Overlay.gbr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]
2026-04-10 esp servo and stepper initial code
2026-04-10 esp servo and stepper start
2026-04-13 belt stopping functionality under camera
    //need to adjust clicks for each of the gates and after how many clicks the belt will stop (when it's under the camera from first breakbeam)
    //need to check about the 21 pinout for blue gate instead of 22 (wasn't working...)
2026-04-15 Current RevPi version
2026-04-26 Add files via upload
    Mechanical Full Assembly
    [Full Assembly.step]
2026-04-26 Current CODESYS Project Archive
2026-05-05 Updated Files to be compatible with JLCPCB
    [BOM-linesorter.csv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]
2026-05-06 jlc pcb bom update
    [BOM-linesorter.csv]
